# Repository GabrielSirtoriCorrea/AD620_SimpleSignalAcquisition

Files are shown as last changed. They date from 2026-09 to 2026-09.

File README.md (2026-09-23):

# Módulo de Amplificação e Aquisição de Sinais com AD620

Este projeto consiste em um módulo de condicionamento, amplificação e aquisição de sinais analógicos de baixa amplitude (como ponte de extensômetros, termopares ou sensores biomédicos) utilizando o **Amplificador de Instrumentação AD620**, gerador de fonte simétrica **ICL7660** e um microcontrolador **ATmega328P** (Arduino Uno) com comunicação serial USART.

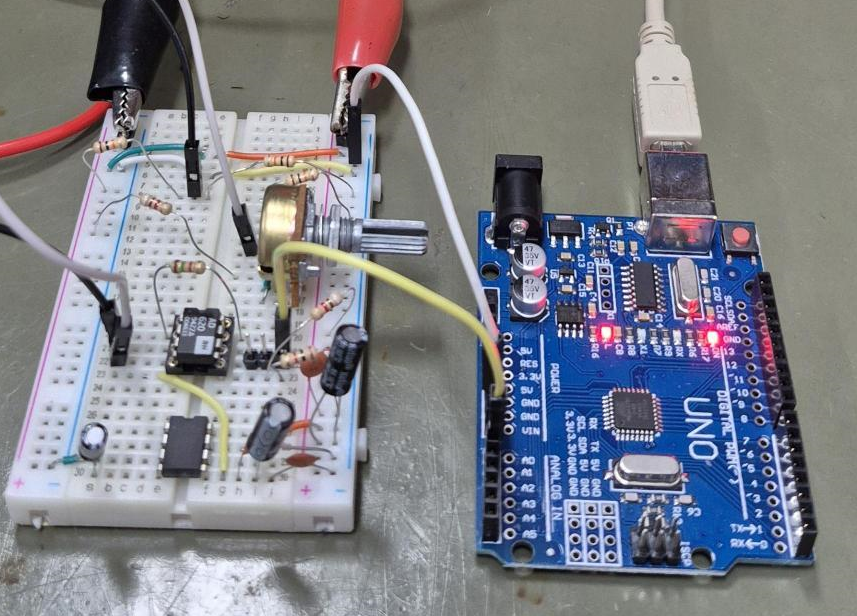
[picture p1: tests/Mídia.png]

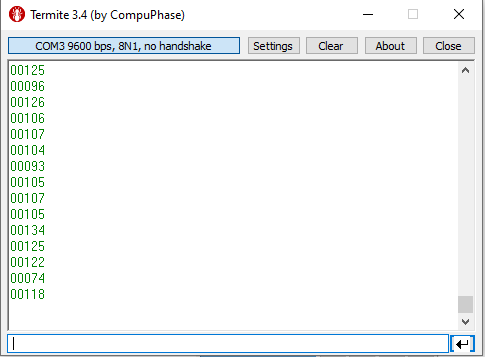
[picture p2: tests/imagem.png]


---

## 📌 Sumário

* [Visão Geral](https://www.google.com/search?q=%23-vis%C3%A3o-geral)
* [Arquitetura de Hardware](https://www.google.com/search?q=%23-arquitetura-de-hardware)
* [Amplificador de Instrumentação (AD620)](https://www.google.com/search?q=%231-amplificador-de-instrumenta%C3%A7%C3%A3o-ad620)
* [Gerador de Tensão Simétrica (ICL7660)](https://www.google.com/search?q=%232-gerador-de-tens%C3%A3o-sim%C3%A9trica-icl7660)
* [Interface de Sinal e Acondicionamento](https://www.google.com/search?q=%233-interface-de-sinal-e-acondicionamento)
* [Processamento e Comunicação (MCU / USB-UART)](https://www.google.com/search?q=%234-processamento-e-comunica%C3%A7%C3%A3o-mcu--usb-uart)

* [Cálculos Teóricos de Ganho e Offset](https://www.google.com/search?q=%23-c%C3%A1lculos-te%C3%B3ricos-de-ganho-e-offset)
* [Firmware](https://www.google.com/search?q=%23-firmware)
* [Estrutura do Código](https://www.google.com/search?q=%23estrutura-do-c%C3%B3digo)
* [Protocolo de Comunicação Serial](https://www.google.com/search?q=%23protocolo-de-comunica%C3%A7%C3%A3o-serial)

* [Lista de Componentes (BOM)](https://www.google.com/search?q=%23-lista-de-componentes-bom)
* [Como Executar o Projeto](https://www.google.com/search?q=%23-como-executar-o-projeto)
* [Autor e Licença](https://www.google.com/search?q=%23-autor-e-licen%C3%A7a)

---

## 🔍 Visão Geral

Sinais analógicos provenientes de sensores diferenciais frequentemente possuem amplitudes muito reduzidas (mV) e necessitam de alta rejeição em modo comum (CMRR), além de condicionamento de tensão antes de serem lidos por um conversor analógico-digital (ADC) de microcontrolador.

O projeto resolve esses desafios combinando:

1. **Ganho Ajustável e Rejeição de Ruído:** Amplificador AD620 configurado com ganho $G \approx 34$.
2. **Alimentação Simétrica ($\pm 5\text{V}$):** O ICL7660 gera um trilho de $-5\text{V}$ a partir da alimentação externa ($+5\text{V}$), permitindo excursão de sinal negativa sem saturação.
3. **Offset Contínuo de Tensão:** Injeção de offset de $\approx 0{,}5\text{V}$ no pino `REF` do AD620 para conformidade com a faixa de leitura do ADC ($0 - 5\text{V}$).
4. **Digitalização e Transmissão:** O conversor ADC interno do ATmega328P amostra o sinal amplificado e o envia periodicamente em formato ASCII via UART (9600 baud rate).

---

## 🛠️ Arquitetura de Hardware

O circuito está dividido em três blocos funcionais principais conforme demonstrado no esquemático elétrico:

### 1. Amplificador de Instrumentação (AD620)

* **CI:** AD620 (U4)
* **Função:** Amplificação diferencial de baixo ruído e alto CMRR.
* **Resistor de Ganho ($R_G$):** $R_{10} = 1{,}5\text{ k}\Omega$.
* **Tensão de Referência (Offset):** Divisor com $R_{13} = 91\text{}\Omega$ e $R_{14} = 10\text{}\Omega$, fornecendo $V_{ref} \approx 0{,}5\text{V}$ ao pino 5.

### 2. Gerador de Tensão Simétrica (ICL7660)

* **CI:** ICL7660 (U3)
* **Função:** Inversor de tensão por capacitores comutados (*switched-capacitor*).
* **Entrada:** $+5\text{V}$ (Alimentação externa).
* **Saída:** $-5\text{V}$ para alimentar o trilho negativo ($V_-$) do AD620.
* **Capacitores de Filtro e Carga:** $C_1, C_5, C_6 = 100\text{ nF}$ e $C_2, C_3, C_4 = 10\mu\text{F}$.

### 3. Interface de Sinal e Acondicionamento

* **Rede de Entrada / Ponte de Teste:** Resistores $R_8 = 10\text{ k}\Omega$, $R_9 = 10\text{ k}\Omega$, $R_{11} = 10\text{ k}\Omega$, $R_{12} = 9{,}1\text{ k}\Omega$ e trimpot $RV_3 = 1\text{ k}\Omega$ para simulação/ajuste do sinal diferencial (`signal+` e `signal-`).

### 4. Processamento e Comunicação (MCU / USB-UART)

* **Microcontrolador:** ATmega328P (placa Arduino Uno R3 - A1).
* **Pino de Leitura ADC:** Canal `A0` (pino 9 da placa).
* **Conversor USB-Serial:** CH340C (U1) para interface com computador via conector USB Type-B (Integrado ao arduino).

---

## 📐 Cálculos Teóricos de Ganho e Offset

### 1. Ganho de Amplificação ($G$)

Pelo datasheet do AD620, o ganho é dado por:

$$G = \frac{49{,}4\text{ k}\Omega}{R_G} + 1$$

Substituindo $R_G = R_{10} = 1{,}5\text{ k}\Omega$:

$$G = \frac{49400}{1500} + 1 = 32{,}93 + 1 \approx 34$$

### 2. Tensão de Offset ($V_{offset}$)

O divisor de tensão ligado ao pino `REF` define o deslocamento de DC de saída:

$$V_{offset} = V_{CC} \times \left( \frac{R_{14}}{R_{13} + R_{14}} \right)$$

$$V_{offset} = 5\text{V} \times \left( \frac{1{,}0\text{ k}\Omega}{9{,}1\text{ k}\Omega + 1{,}0\text{ k}\Omega} \right) = 5 \times \frac{1}{10{,}1} \approx 0{,}495\text{V} \approx 0{,}5\text{V}$$

### 3. Equação Geral da Saída ($V_{output}$)

$$V_{output} = (V_{signal+} - V_{signal-}) \times G + V_{offset}$$

$$V_{output} = (V_{signal+} - V_{signal-}) \times 34 + 0{,}5\text{V}$$

**Exemplo Prático (presente no esquemático):**
Para um sinal diferencial de entrada $\Delta V_{in} = 0{,}1\text{V}$:

$$V_{output} = (0{,}1\text{V}) \times 34 + 0{,}5\text{V} = 3{,}4\text{V} + 0{,}5\text{V} = 3{,}9\text{V}$$

---

## 💻 Firmware

O código-fonte foi desenvolvido em linguagem **C puro** para a arquitetura AVR, sem dependências do framework Arduino (utilizando manipulação de registradores e drivers modulares de USART e ADC).

### Código-Fonte Principal (`main.c`)

### Protocolo de Comunicação Serial

* **Baud Rate:** 9600 bps
* **Data Bits:** 8 bits
* **Paridade:** Nenhuma
* **Stop Bits:** 1
* **Formato do Pacote:** String de 5 caracteres numéricos preenchida com zeros à esquerda, finalizada pelo caractere `0x0A` (`\n`).
* *Exemplo de saída:* `00798\n` (Valor bruto do ADC de 10 bits correspondente a $\approx 3{,}9\text{V}$).

---

## 📦 Lista de Componentes (BOM)

| Componente | Designador | Descrição | Qtd |
| --- | --- | --- | --- |
| **AD620** | U4 | Amplificador de Instrumentação DIP-8 / SOIC-8 | 1 |
| **ICL7660** | U3 | Conversor de Tensão Inversor de Carga Comutada | 1 |
| **CH340C** | U1 | Conversor USB para Serial UART | 1 |
| **ATmega328P / Arduino Uno** | A1 | Microcontrolador de 8-bits AVR | 1 |
| **Resistor 1.5 kΩ** | R10 | Resistor de ajuste de ganho ($R_G$), 1/4W 1% | 1 |
| **Resistor 10 Ω** | R14 | Resistor do divisor de offset, 1/4W 1% | 1 |
| **Resistor 91 Ω** | R12, R13 | Resistores de condicionamento/offset, 1/4W 1% | 1 |
| **Resistor 9.1 kΩ** | R12, R13 | Resistores de condicionamento/offset, 1/4W 1% | 1 |
| **Resistor 10 kΩ** | R8, R9, R11 | Resistores de ponte de entrada, 1/4W 1% | 3 |
| **Trimpot 1 kΩ** | RV3 | Potenciômetro multivoltas para ajuste fino | 1 |
| **Capacitor 100 nF** | C1, C5, C6 | Capacitor Cerâmico Desacoplamento / Filtro | 3 |
| **Capacitor Eletrolítico 10 µF** | C2, C3, C4 | Capacitor Eletrolítico da Fonte Simétrica | 3 |
| **Conector USB** | J1 | Conector USB Type-B / Micro USB | 1 |

---

## 🚀 Como Executar o Projeto

### Pré-requisitos

* **Compilador:** `avr-gcc`
* **Hardware:** Protoboard com os componentes listados
* **Software Monitor Serial:** Termite, PuTTY, Serial Plotter, Arduino Serial Monitor ou script Python

### Compilação e Gravação (via Terminal / Makefile)

O projeto pode ser compilado e gravado através da Arduino IDE, makefile, diretamente pelo gravador `avrdude` ou pelo Platform IO.

---

## 👨‍💻 Autor e Licença

**Desenvolvido por:** Gabriel Sirtori Corrêa

**Projeto:** Simple Signal Acquisition with AD620 Instrumentation Amplifier

**Software EDA:** KiCad 10.0.0

Licenciado sob a [MIT License](https://www.google.com/search?q=LICENSE).

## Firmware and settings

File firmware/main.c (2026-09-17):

#include "macros.h"
#include "drivers/usart.h"
#include "drivers/adc.h"

int main(void) {
	cli();
	usart_init(9600, 0);
	adc_init();
    sei();
	char byte_rcv = 0x00;
	char string[SIZEBUFF] = {0X00};
	uint16_t i = 0;
	uint16_t adc_value = 12345;
	char byte0;
	char byte1;
	char str[6] = ""; // 5 dígitos + '\0'

    while (1){
		adc_value = adc_read(0);
		str[0] = (char) ((adc_value/10000) + '0');
		str[1] = (char) ((adc_value/1000) % 10 + '0');
		str[2] = (char) ((adc_value/100) % 10 + '0');
		str[3] = (char) ((adc_value/10) % 10 + '0');
		str[4] = (char) (adc_value % 10 + '0');
		str[5] = '\0';

		byte0 = (char)(adc_value & 0x00FF);
		byte1 = (char)((adc_value & 0xFF00) >> 8);
	

		for(i=0; usart_cnt()>0; i++){
			string[i] = usart_read();
		}
		for(i+1;i<=SIZEBUFF;i++){
			string[i] = 0x00;
		}

		for(uint16_t i=0; str[i]!='\0'; i++)
				usart_write(str[i]);
		usart_write(0x0A);
		
		_delay_ms(500);

    }
}

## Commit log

2026-09-15 LCD Display
    [AD620_SimpleSignalAcquisition.kicad_sch]
2026-09-16 Implementacao de firmware de leitura
    [AD620_SimpleSignalAcquisition.kicad_sch]
2026-09-17 Serial communication
    [AD620_SimpleSignalAcquisition.kicad_sch]
2026-09-23 Updating schematic
    [AD620_SimpleSignalAcquisition.kicad_sch]
